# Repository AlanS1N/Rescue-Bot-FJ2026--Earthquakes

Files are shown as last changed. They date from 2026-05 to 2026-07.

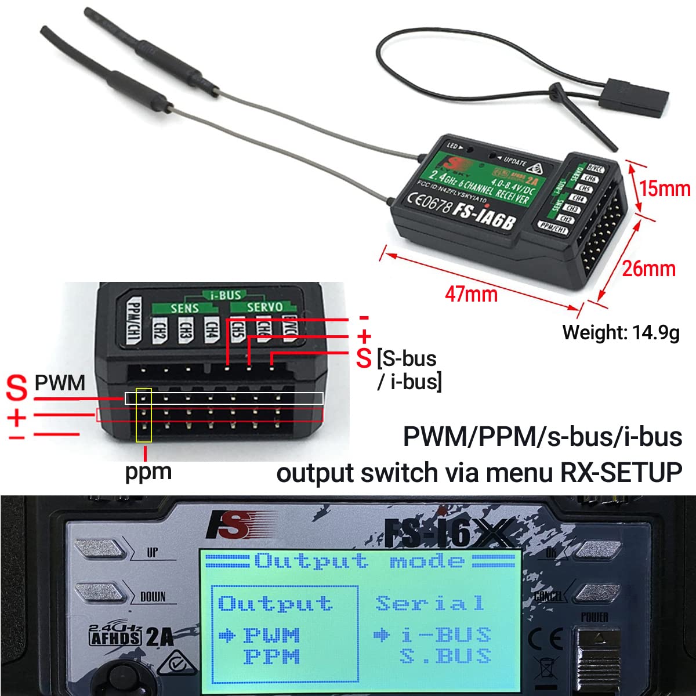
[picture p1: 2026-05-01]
Motor Movement/Image - FlySky Setup Reference.jpg

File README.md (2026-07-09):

# Design and Implementation of a Mobile Robot for Search, Rescue, and Structural Diagnostics in Disaster Scenarios
>[!WARNING]
>This is Work in Progress Project at the Tecnológico de Monterrey Campus Puebla.

banner-RescueBot





 Table of Contents

- [Project Overview](#project-overview)
- [Screenshots and Progress](#screenshots-and-progress)
- [Circuit Connections](#circuit-connections)
- [Materials](#materials)
- [Future Goals](#future-goals)

---

# Project Overview

This project focuses on the analysis of structural damages and failures caused by disasters (earthquakes, landslides, etc.) to identify operational needs for search and rescue in high-risk zones. Based on these findings, we designed and built a terrestrial mobile robot that _will serve both as a machine_ for entering and exploring without endangering first responders, _and as a tool to diagnose estructural damages_ using artificial computer vision.

The system **will be** validated in a simulated disaster scenario to evaluate technical performance, exploration efficiency, and its utility in supporting rescue missions and structural diagnostics.

📜 Click here to <a href="https://www.overleaf.com/read/qfjzchcjjjqq#3e95bf"> VIEW the paper developed alongside the documentation in Github.</a> (WORK IN PROGRESS)

📷 Click here to<a href="https://1024terabox.com/s/1G64Ih9HwfPtlZVFDbBaQSw"> DOWNLOAD the the DATASET used to train the vision system</a>, provided by Dr. Romeo Ballinas González.

👁️ Click here to<a href="https://1024terabox.com/s/1AKwh-wiAku7Wo5QE4bYNWA"> DOWNLOAD the the VISION SYSTEM LOCAL FILES used to train the vision system.</a> (40.6 GiB)

**Key Features:**
  1. Teleoperated movement.
  2. Video transmission through RF.
  3. Camara movement throguh head tracking.
  4. Trained algorithm to detect and diagnose structural damages.
  5. Rocker bogie suspension.

# Screenshots and Progress

<table>
  <tr>
    <td>
      
    </td>
    <td>
      
    </td>
  </tr>
  <tr>
    <td>
      
    </td>
    <td>
      
    </td>
  </tr>
</table>

👉 [Click here to see development logs and check out the current progress](./.docs/progress.md)

# Circuit Connections
The complete circuit diagram is shown below:

Captura desde 2026-06-09 13-00-33

# Materials

The material list used is listed below:

| Name | Units |
|---|---|
| JGB37-520B | 6 |
| Servomotor MG995 | 1 |
| Servomotor MG996 | 1 |
| H Bridge BTS7960 IBT_2  | 2 |
| GY-BNO085 | 1 |
| ESP32 DEVKIT 30 Pines | 2 |
| Jetson Nano Ori | 1 |
| FPV Set TS5823Pro | 1 |
| Logitech C920 Webcam | 1 |
| EMAX Transporter 2 | 1 |
| FlySky FS-i6x Control | 1 |
| FlySky FS-iA6 Rx | 1 |
| PLA Filament | 1 |
| TPU Filament | 1 |
| Perf. phenolic board | 2 |
| Screws(various lengths) |  ±14  |

# Future Goals
This project is planned to be worked on further more with other students at Tecnológico de Monterrey Campus Puebla, under the supervision of Dr. Roberto R. Flores Quintero.

Some current future goals involve:
- 🧠 Deeper training and testing of the computer vision system.
- 🔧 Redisign the structure to for increased stability and access to components
- 🌡️ Adding thermal vision for detecting gases and possible life signals.
- 🕶️ Developing a VR simulated environment.

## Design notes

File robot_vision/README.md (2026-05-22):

# Robot Vision

README de chill para correr la vision del robot en la Jetson y entender como funciona lo del screenshot.

## Que hace

Esta carpeta trae el clasificador de dano/no dano para la camara del robot.

El modelo es un YOLO classifier de Ultralytics. Ojo: no detecta cajas ni marca exactamente donde esta el dano; ve el frame completo y decide una clase:

```text
damage
no_damage
```

El script principal es:

```text
infer_camera.py
```

Ese script abre la camara, corre el modelo en vivo y, si esta conectado al ESP32 por serial, tambien escucha triggers para guardar screenshot.

## Lo del screenshot

Si, esta version ya tiene el trigger.

La idea es:

```text
ESP32 manda por serial: PHOTO_TRIGGER
Python lo lee en infer_camera.py
Python guarda la foto actual con la prediccion dibujada
Python guarda tambien un JSON con metadata
```

El texto tiene que llegar exactamente asi:

```text
PHOTO_TRIGGER
```

Cuando llega, Python guarda archivos en:

```text
robot_vision/captures/
```

Ejemplo de salida:

```text
captures/trigger-20260521-154233.jpg
captures/trigger-20260521-154233.json
```

El `.jpg` es la imagen con el overlay de la prediccion. El `.json` trae cosas como clase, confianza, status y ruta de la imagen.

Ejemplo del mensaje que imprime Python cuando guarda:

```text
photo_saved metadata=captures/trigger-20260521-154233.json class=damage conf=0.932
```

## Archivos importantes

```text
robot_vision/
|-- infer_camera.py        -> corre camara + modelo + trigger PHOTO_TRIGGER
|-- smoke_test.py          -> prueba rapida con una imagen
|-- requirements.txt       -> dependencias de Python
|-- README.md              -> este archivo
|-- models/
|   `-- bestfinal.pt       -> modelo recomendado
`-- captures/              -> aqui se guardan screenshots cuando hay trigger
```

Para correr en el robot, lo importante es:

```text
infer_camera.py
smoke_test.py
requirements.txt
models/bestfinal.pt
```

No hace falta mover datasets, runs, imagenes de entrenamiento ni cosas de preparacion.

## Instalar en la Jetson

Desde el repo del robot:

```bash
cd robot_vision
python3 -m venv .venv
source .venv/bin/activate
pip install -r requirements.txt
```

Si la Jetson ya tiene PyTorch/Ultralytics instalado en otro ambiente, puedes usar ese ambiente y saltarte el `.venv`.

Dependencias de esta carpeta:

```text
ultralytics
opencv-python
pyserial
```

## Probar que el modelo carga

Usa cualquier imagen:

```bash
python3 smoke_test.py /ruta/a/imagen.jpg
```

Salida esperada:

```text
class=damage conf=0.932
```

o:

```text
class=no_damage conf=0.884
```

Si esto funciona, el modelo esta cargando bien.

## Probar camara sin ESP32

Primero prueba que la camara abre:

```bash
python3 infer_camera.py --camera 0 --show
```

Para cerrar la ventana, presiona `q`.

Si no abre, prueba otra camara:

```bash
python3 infer_camera.py --camera 1 --show
```

Modo sin ventana, mas parecido a integracion real:

```bash
python3 infer_camera.py --camera 0
```

El script imprime algo cada medio segundo:

```text
ok class=damage label='Damage' conf=0.932
ok class=no_damage label='No damage' conf=0.884
```

Puedes cambiar cada cuanto imprime:

```bash
python3 infer_camera.py --camera 0 --print-every 0.2
```

Y puedes pedir confianza minima:

```bash
python3 infer_camera.py --camera 0 --min-conf 0.70
```

Si la confianza queda abajo de eso, imprime:

```text
low_conf class=damage label='Damage' conf=0.621
```

## Probar camara CSI con GStreamer

Si la Jetson usa camara CSI, puedes pasar un pipeline GStreamer como `--camera`.

Ejemplo base:

```bash
python3 infer_camera.py --camera "nvarguscamerasrc ! video/x-raw(memory:NVMM), width=640, height=480, framerate=30/1 ! nvvidconv ! video/x-raw, format=BGRx ! videoconvert ! video/x-raw, format=BGR ! appsink" --show
```

Si usas USB webcam, normalmente basta con `--camera 0`.

## Probar el trigger del screenshot en la Jetson

Conecta el ESP32 por USB y revisa que puerto le dio Linux:

```bash
ls /dev/ttyUSB* /dev/ttyACM*
```

Puede ser algo como:

```text
/dev/ttyUSB0
```

o:

```text
/dev/ttyACM0
```

Corre vision con serial:

```bash
python3 infer_camera.py --camera 0 --serial-port /dev/ttyUSB0 --baud 115200 --show
```

Si tu puerto es otro:

```bash
python3 infer_camera.py --camera 0 --serial-port /dev/ttyACM0 --baud 115200 --show
```

Cuando el ESP32 mande `PHOTO_TRIGGER`, Python debe imprimir:

```text
photo_saved metadata=... class=... conf=...
```

Luego revisa:

```bash
ls captures
```

Deberias ver un `.jpg` y un `.json` por cada trigger.

## Probar trigger sin ESP32 real

Si quieres probar solo la parte de Python/serial sin depender del codigo del ESP32, puedes usar dos terminales con un puerto serial virtual. En Jetson normalmente sirve `socat`.

Instala si hace falta:

```bash
sudo apt install socat
```

Terminal 1:

```bash
socat -d -d pty,raw,echo=0 pty,raw,echo=0
```

Eso imprime dos puertos, por ejemplo:

```text
/dev/pts/3
/dev/pts/4
```

Terminal 2, corre vision usando el primer puerto:

```bash
python3 infer_camera.py --camera 0 --serial-port /dev/pts/3 --show
```

Terminal 3, manda el trigger por el segundo puerto:

```bash
printf "PHOTO_TRIGGER\n" > /dev/pts/4
```

Si todo esta bien, se guarda la captura en `captures/`.

## Comando recomendado para integracion real

Para el robot, sin ventana:

```bash
python3 infer_camera.py --camera 0 --serial-port /dev/ttyUSB0 --baud 115200 --capture-dir captures --min-conf 0.70
```

Con ventana para debug:

```bash
python3 infer_camera.py --camera 0 --serial-port /dev/ttyUSB0 --baud 115200 --capture-dir captures --min-conf 0.70 --show
```

## Argumentos utiles

```text
--model         Ruta al modelo .pt. Default: models/bestfinal.pt
--camera        Indice de camara o pipeline GStreamer. Default: 0
--width         Ancho de captura. Default: 640
--height        Alto de captura. Default: 480
--show          Muestra ventana de OpenCV
--min-conf      Confianza minima para status ok
--print-every   Cada cuantos segundos imprime prediccion
--serial-port   Puerto del ESP32, por ejemplo /dev/ttyUSB0
--baud          Baud rate del ESP32. Default: 115200
--capture-dir   Carpeta donde se guardan screenshots. Default: captures
```

## Problemas comunes

Si la camara no abre:

```bash
python3 infer_camera.py --camera 1 --show
```

Si el serial no abre, revisa permisos:

```bash
ls -l /dev/ttyUSB0
```

Puede que necesites agregar tu usuario al grupo `dialout`:

```bash
sudo usermod -a -G dialout $USER
```

Luego cierra sesion y vuelve a entrar.

Si no se guarda screenshot:

```text
1. Confirma que estas pasando --serial-port.
2. Confirma que el ESP32 esta mandando exactamente PHOTO_TRIGGER con salto de linea.
3. Confirma que el baud coincide, normalmente 115200.
4. Mira la consola de Python: debe aparecer photo_saved.
5. Revisa la carpeta captures/.
```

Si el modelo no carga:

```text
1. Revisa que exista models/bestfinal.pt.
2. Corre smoke_test.py con una imagen.
3. Confirma que ultralytics este instalado en el ambiente activo.
```

## Mini resumen

Para probar rapido en Jetson:

```bash
cd robot_vision
source .venv/bin/activate
python3 smoke_test.py /ruta/a/imagen.jpg
python3 infer_camera.py --camera 0 --show
python3 infer_camera.py --camera 0 --serial-port /dev/ttyUSB0 --baud 115200 --show
```

Y cuando el ESP32 mande:

```text
PHOTO_TRIGGER
```

Python toma el frame actual, corre/usa la prediccion actual, guarda screenshot y metadata en:

```text
captures/
```

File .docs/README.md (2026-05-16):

# Design and Implementation of a Mobile Robot for Search, Rescue, and Structural Diagnostics in Disaster Scenarios
>[!WARNING]
>This is Work in Progress Project at the Tecnológico de Monterrey Campus Puebla.

banner-RescueBot





 Table of Contents

- [Project Overview](#project-overview)
- [Screenshots and Progress](#screenshots-and-progress)
- [Circuit Connections](#circuit-connections)
- [Materials](#materials)
- [Future Goals](#future-goals)

---

# Project Overview

This project focuses on the analysis of structural damages and failures caused by disasters (earthquakes, landslides, etc.) to identify operational needs for search and rescue in high-risk zones. Based on these findings, we designed and built a terrestrial mobile robot that _will serve both as a machine_ for entering and exploring without endangering first responders, _and as a tool to diagnose estructural damages_ using artificial computer vision.

The system **will be** validated in a simulated disaster scenario to evaluate technical performance, exploration efficiency, and its utility in supporting rescue missions and structural diagnostics.

📜 (WIP) The paper developed alongside the documentation in Github can be viewwed <a href="https://www.overleaf.com/read/qfjzchcjjjqq#3e95bf">by clicking here.</a>

**Key Features:**
  1. Teleoperated movement.
  2. Video transmission through RF.
  3. Camara movement throguh head tracking.
  4. Trained algorithm to detect and diagnose structural damages.
  5. Rocker bogie suspension.

# Screenshots and Progress

<table>
  <tr>
    <td>
      
    </td>
    <td>
      
    </td>
  </tr>
  <tr>
    <td>
      
    </td>
    <td>
      
    </td>
  </tr>
</table>

👉 [Click here to see development logs and check out the current progress](./progress.md)

# Circuit Connections
The complete circuit diagram is shown below:

Captura desde 2026-05-14 22-33-53

# Materials

The material list used is listed below:

| Name | Units |
|---|---|
| JGB37-520B | 6 |
| Servomotor MG995 | 2 |
| H Bridge BTS7960 IBT_2  | 2 |
| GY-BNO085 | 1 |
| ESP32 DEVKIT 30 Pines | 2 |
| FPV Set TS5823Pro | 1 |
| Logitech C920 Webcam | 1 |
| EMAX Transporter 2 | 1 |
| 1K Ohms Resistor | 2 |

# Future Goals
This project is planned to be worked on further more with other students at Tecnológico de Monterrey Campus Puebla, under the supervision of Dr. Roberto R. Flores Quintero.

Some current future goals involve:
- 🧠 Deeper training and testing of the computer vision system.
- 🌡️ Adding thermal vision for detecting gases and possible life signals.
- 🔧 Adding more useful sensors to the robot.
- 🕶️ Developing a VR simulated environment.

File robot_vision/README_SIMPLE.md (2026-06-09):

# Robot Vision - Guía rápida para la Jetson

Esto es para que pruebes primero el programa y luego lo dejes arrancar solo al encender.

## Paso 1 - Ir a la carpeta correcta

```bash
cd ~/Desktop/rescue_robot/Final_old/robot_vision
```|

## Paso 2 - Activar el entorno virtual

```bash
source .venv/bin/activate
```

Si no existe `.venv`, créalo con:

```bash
python3 -m venv .venv
source .venv/bin/activate
pip install -r requirements.txt
```

## Paso 3 - Arreglar la compatibilidad de NumPy

Tu error actual dice que NumPy 2.x no funciona con Torch/Ultralytics.

Haz esto dentro del venv:

```bash
python3 -m pip install --upgrade pip
python3 -m pip install "numpy<2"
python3 -m pip install -r requirements.txt
```

Si el error persiste y todavía ve paquetes desde `/home/<usuario>/.local`, fuerza que Python NO use paquetes de usuario:

```bash
export PYTHONNOUSERSITE=1
python3 -m pip install "numpy<2"
python3 -m pip install -r requirements.txt
```

### Si sigues con problemas, recrea el venv limpio

```bash
cd ~/Desktop/rescue_robot/Final_old/robot_vision
rm -rf .venv
python3 -m venv .venv
source .venv/bin/activate
python3 -m pip install --upgrade pip
export PYTHONNOUSERSITE=1
python3 -m pip install "numpy<2"
python3 -m pip install -r requirements.txt
```

Con eso se asegura que el entorno use versiones compatibles y no mezcle paquetes de usuario.

## Paso 4 - Probar el programa manualmente

Antes de tocar el service, prueba que esto funcione:

```bash
python3 infer_camera.py --camera 0
```

Si estás delante de la Jetson y quieres ver la cámara:

```bash
SHOW_WINDOW=true python3 infer_camera.py --camera 0
```

### Qué debe pasar

- El script debe arrancar y quedarse ejecutando
- Debe leer la cámara `/dev/video0` o el índice correcto
- Debe mostrar mensajes de `ok` o `low_conf` cada cierto tiempo

Si se cierra rápido, no sigas aún con el servicio.

## Paso 4.1 - Si no abre la cámara

Si ves este error:

```text
No pude abrir la camara. Prueba --camera 1 o revisa el pipeline.
```

haz esto:

```bash
ls /dev/video*
v4l2-ctl --list-devices
```

Si aparece `/dev/video1`, prueba:

```bash
SHOW_WINDOW=true python3 infer_camera.py --camera 1
```

Si tu cámara es una cámara NVIDIA/Jetson integrada, prueba la pipeline de GStreamer:

```bash
python3 infer_camera.py --camera "nvarguscamerasrc ! video/x-raw(memory:NVMM), width=640, height=480, framerate=30/1 ! nvvidconv ! video/x-raw, format=BGRx ! videoconvert ! video/x-raw, format=BGR ! appsink"
```

Si `v4l2-ctl` no existe, instálalo con:

```bash
sudo apt install v4l-utils
```

Solo sigue al servicio cuando puedas abrir la cámara sin error.

## Paso 5 - Configurar el service para arrancar al boot

```bash
chmod +x start_vision.sh
sudo cp robot-vision.service /etc/systemd/system/
sudo systemctl daemon-reload
sudo systemctl enable robot-vision.service
sudo systemctl restart robot-vision.service
```

## Paso 6 - Verificar el servicio

```bash
sudo systemctl status robot-vision.service
sudo journalctl -u robot-vision.service -f
```

Si ves que el service sigue reiniciando y saliendo con `status=1`, entonces el programa aún no corre bien.

## Paso 7 - Probar reinicio de la Jetson

Si ya funciona manualmente y el service se mantiene activo:

```bash
sudo reboot
```

Luego, al volver a conectar por SSH:

```bash
sudo systemctl status robot-vision.service
sudo journalctl -u robot-vision.service -n 50 --no-pager
```

## Nota importante

- El service no debe usar `--show` automáticamente.
- Si quieres ver la pantalla, hazlo manualmente con `SHOW_WINDOW=true`.
- Primero asegúrate de que `python3 infer_camera.py --camera 0` funcione.
- Solo después habilita `systemctl enable robot-vision.service`.

## Diagnóstico rápido

Si algo falla, revisa esto:

```bash
ls -l models/bestfinal.pt
python3 infer_camera.py --camera 0 2>&1 | tee /tmp/infer_debug.txt
```

Eso te dirá si falta el modelo o si hay error de librerías.

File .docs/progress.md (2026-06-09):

# 📚 **Development Progress**
👉 [Back to Main Description](https://github.com/AlanS1N/Rescue-Bot-FJ2026--Earthquakes)

### Table of Contents
- [CAD Design](#-cad-design)
- [Electronics](#-electronics)
- [Computer Vision](#-computer-vision)
- [Teleoperated Control](#-teleoperated-control)
- [Head Tracking](#-head-tracking)
- [Batteries](#-batteries-implementation)
- [Complete Integration](#-complete-integration)
---

---
# 🛠 CAD Design
### 📌 Progress
- Initial chassis structure completed: Made "legs" out of PVC and component box of PLA.
- Wheels and rims installed: Both custom designed, rims printed with PLA and wheels printed with TPU.
- Rocker-bogie dimensions adjusted: Alligned the wheels.

### 🖼 Preview (Solidworks)


---

# ⚡ Electronics
### 📌 Progress
- FlySky components integrated: RX and controller fully integrated and tested.
- PCBs for circuits completed: Made custom PCB for ESP32 with IMU.
- Servo mechanism with IMU implemented: Cameras slots and movement implemented.

### 🎥 Video
Video_Github

---

# 💻 Computer Vision
### 📌 Progress
- Database collected: Received database for training model.
- Yolo model prototype: Functional prototype tested.

### 🎥 Video
Modelo_Test

---

# 🎮 Teleoperated Control
### 📌 Progress
- Motors fully operational: H-Bridges connected to all 6 motors and working.
- ESP and controller connected: Recieves signal and moves motors in given direction.

### 🎥 Video
Movement_Tests

---

# 🥽 Head Tracking
### 📌 Progress
- ESP-Now protocol implemented: Communication without Wi-Fi nor Bluetooth between circuits.
- Servos moving according to IMU.

### 🎥 Video
Visor_TEst

---

# 🔋 Batteries implementation
### 📌 Progress
- Soldered cables to energize dedicated components.
- Added switches to turn on energy easily,

### 🖼 Preview (Solidworks)
Batteries

---

# ✅ Complete Integration
### 📌 Progress
- Make adjustments for all components to be interconnected and functional.
- ESP32 recieves communication through ESP-NOW and the controller.
- ESP32 controls all logic succesfully.

### 🎥 Video
Integration

---
👉 [Back to Main Description](https://github.com/AlanS1N/Rescue-Bot-FJ2026--Earthquakes)

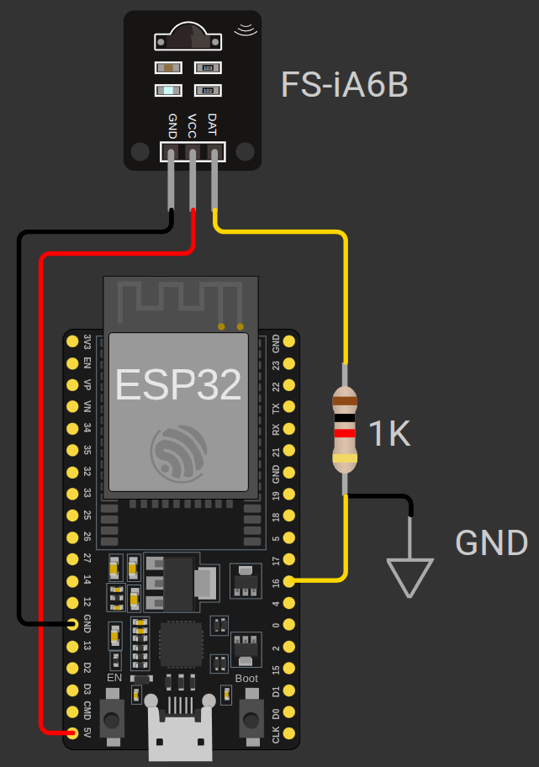
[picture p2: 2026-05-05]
Motor Movement/Image - FS-iA6B to ESP32.png

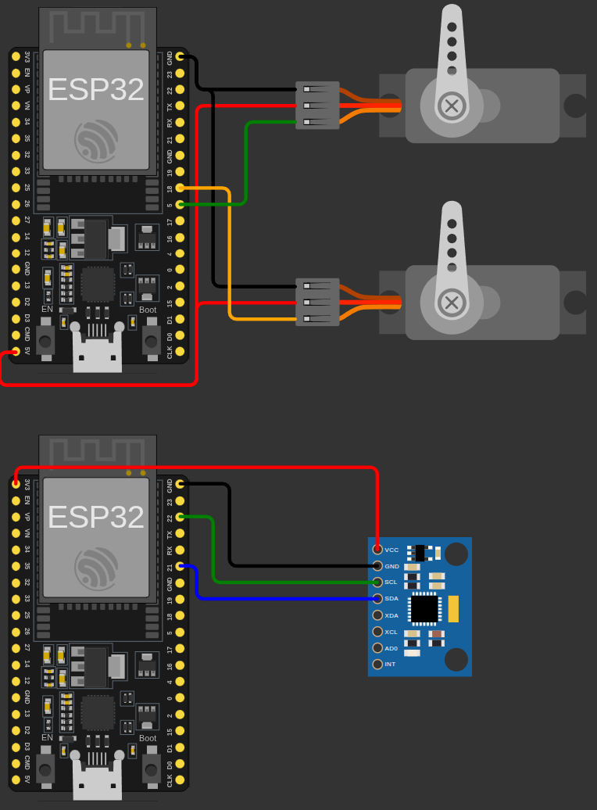
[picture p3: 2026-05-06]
Camera Head Tracking/Image - Circuit Diagram (1).png

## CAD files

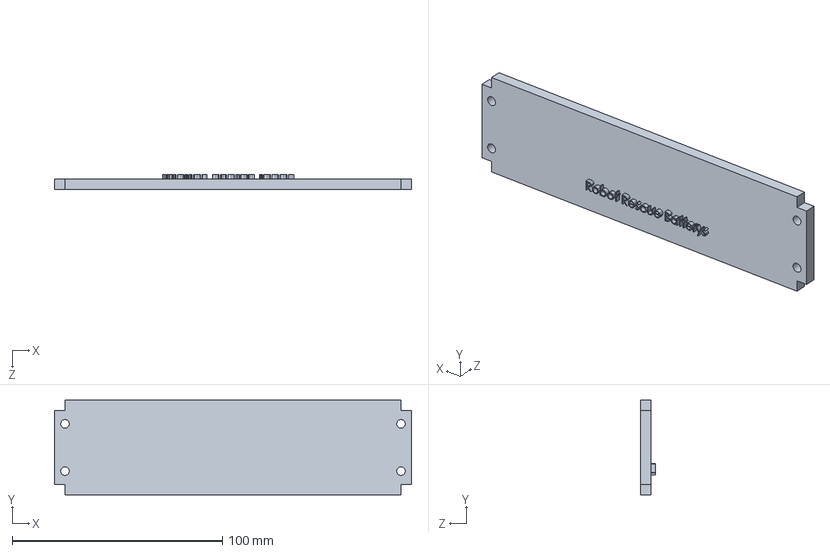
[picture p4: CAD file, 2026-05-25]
.3D Models/TapaCajaPilas.SLDPRT
170.0 x 45.0 x 7.00 mm

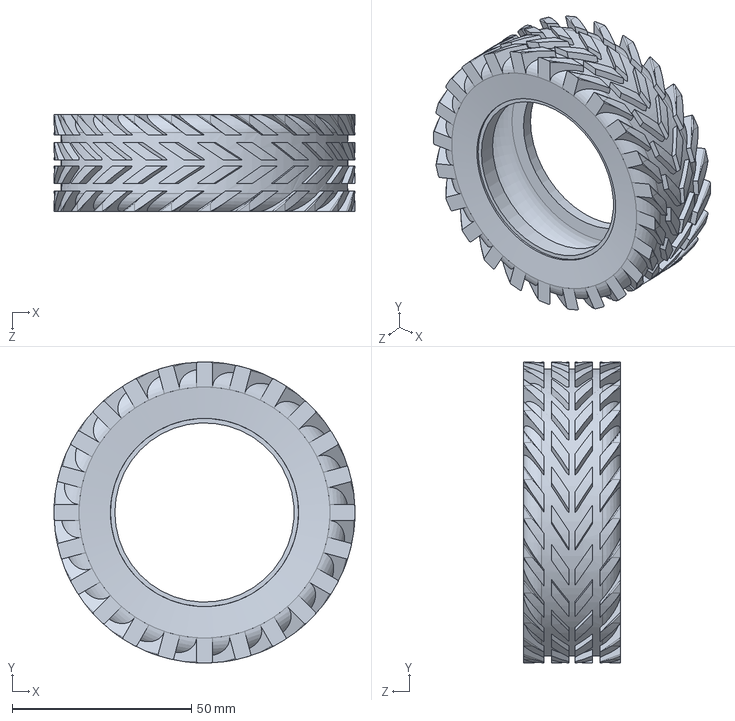
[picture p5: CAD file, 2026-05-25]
.3D Models/LlantaFinal.SLDPRT
84.0 x 84.0 x 27.0 mm

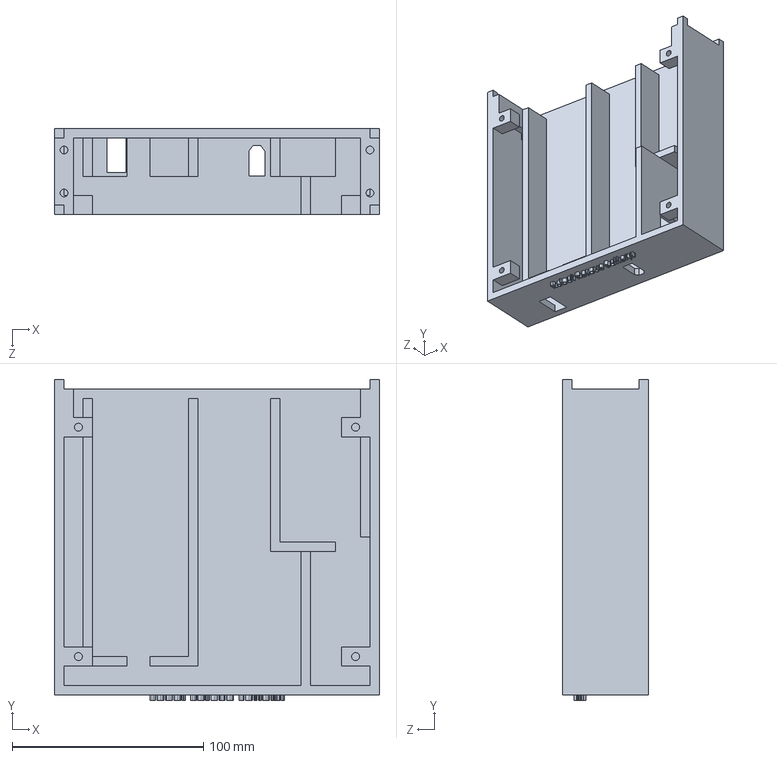
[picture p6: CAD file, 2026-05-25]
.3D Models/CajaParaPilas1.SLDPRT
170.0 x 168.0 x 45.0 mm

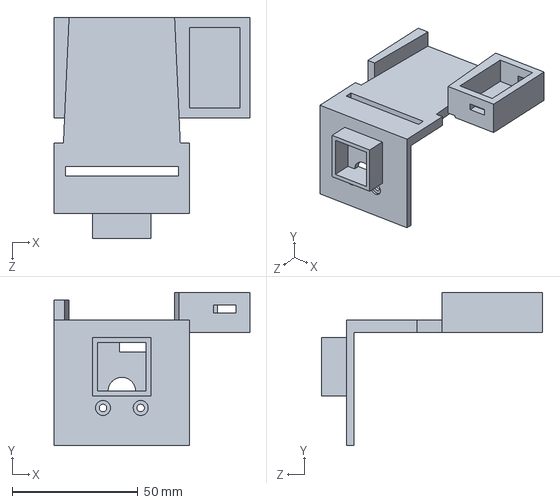
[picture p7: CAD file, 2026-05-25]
.3D Models/soportecamfinal.SLDPRT
78.0 x 61.0 x 88.0 mm

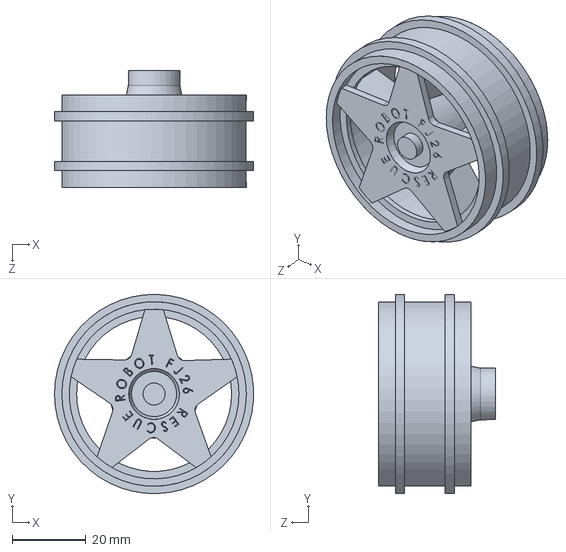
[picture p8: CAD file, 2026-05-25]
.3D Models/llanta roja p2.SLDPRT
53.9 x 54.0 x 31.6 mm

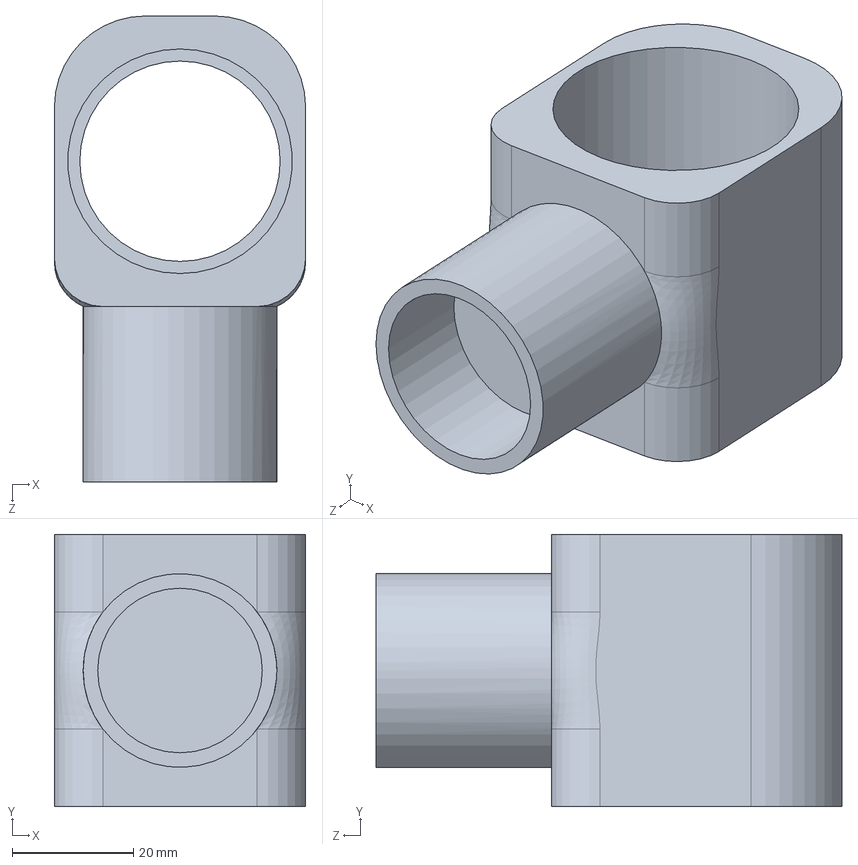
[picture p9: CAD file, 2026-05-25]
.3D Models/MotorEncople.SLDPRT
41.5 x 45.0 x 77.0 mm

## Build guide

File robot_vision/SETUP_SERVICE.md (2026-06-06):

# Setup Automático - Robot Vision Service

## ¿Qué hace?
- **Corre automáticamente al iniciar la Jetson** sin necesidad de SSH
- **Detecta automáticamente el puerto serial** (USB0 o ACM0)
- **Guarda logs** en `robot_vision/logs/` con timestamp
- **Reinicia automáticamente** si falla
- **Cámara 0 fija** (sin necesidad de cambiar parámetros)
- **Corre headless**: no usa `--show` en el servicio systemd

## Instalación en la Jetson

### 1. Copiar archivos
```bash
cd ~/robot_vision
# Los archivos ya deben estar aquí:
# - start_vision.sh
# - robot-vision.service
```

### 2. Dar permisos al script
```bash
chmod +x ~/robot_vision/start_vision.sh
```

### 3. Copiar service a systemd
```bash
sudo cp ~/robot_vision/robot-vision.service /etc/systemd/system/
```

### 4. Recargar systemd
```bash
sudo systemctl daemon-reload
```

### 5. Habilitar el service (para que corra al boot)
```bash
sudo systemctl enable robot-vision.service
```

### 6. Iniciar el service (opcional, si no quieres esperar al reboot)
```bash
sudo systemctl start robot-vision.service
```

---

## Comandos útiles

### Ver estado del service
```bash
sudo systemctl status robot-vision.service
```

### Ver logs en vivo
```bash
sudo journalctl -u robot-vision.service -f
```

### Ver logs de una hora específica
```bash
sudo journalctl -u robot-vision.service --since "2026-06-04 10:00:00"
```

### Ver logs guardados en archivo
```bash
ls ~/robot_vision/logs/
cat ~/robot_vision/logs/vision_20260604_101234.log
```

### Parar el service
```bash
sudo systemctl stop robot-vision.service
```

### Reiniciar el service
```bash
sudo systemctl restart robot-vision.service
```

### Deshabilitar el service (no corra al boot)
```bash
sudo systemctl disable robot-vision.service
```

---

## Troubleshooting

### El service no inicia
```bash
sudo systemctl status robot-vision.service
# Ver el error específico
```

### Permisos del puerto serial
Si ves "Permission denied" en los logs:
```bash
sudo usermod -a -G dialout jetson
# Luego logout y login de nuevo
```

### Ver si el puerto está siendo detectado
```bash
ls /dev/ttyUSB* /dev/ttyACM*
```

### Ver logs del service en tiempo real
```bash
sudo journalctl -u robot-vision.service -f --no-pager
```

### El venv no se crea bien
```bash
# Borrar el venv y dejar que el script lo recree
rm -rf ~/robot_vision/.venv
sudo systemctl restart robot-vision.service
```

---

## Automatización adicional (opcional)

Si quieres **parar el service sin usar SSH**:

1. Crea un archivo vacío que signifique "parar"
2. Modifica el script para checarlo

O usa:
```bash
# Parar remotamente
ssh jetson@<IP> "sudo systemctl stop robot-vision.service"
```

---

## Flujo después de boot

1. Jetson arranca
2. systemd inicia el service automáticamente
3. Script detecta puerto serial
4. Corre `infer_camera.py` con los parámetros correctos
5. Logs se guardan en `logs/vision_TIMESTAMP.log`
6. Si falla, reintentar después de 10 segundos

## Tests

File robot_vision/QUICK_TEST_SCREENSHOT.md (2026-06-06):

# Prueba rapida: trigger + screenshot en Jetson

Objetivo: comprobar que el ESP32 manda el trigger y que la Jetson guarda aunque sea una screenshot.

## 1. Cargar el codigo al ESP32

En Arduino IDE:

1. Abre el sketch del ESP32.
2. Selecciona la placa ESP32 correcta.
3. Selecciona el puerto USB del ESP32.
4. Sube el codigo.

Lo importante es que, cuando quieras tomar foto, el ESP32 mande esto por Serial:

```cpp
Serial.println("PHOTO_TRIGGER");
```

El baud debe coincidir con Python. Recomendado:

```cpp
Serial.begin(115200);
```

## 2. Conectar ESP32 a la Jetson

Conecta el ESP32 a la Jetson por USB.

En la Jetson corre:

```bash
ls /dev/ttyUSB* /dev/ttyACM*
```

Normalmente sera uno de estos:

```text
/dev/ttyUSB0
/dev/ttyACM0
```

Ese es el puerto que vas a usar en `--serial-port`.

## 3. Entrar a robot_vision

```bash
cd robot_vision
source .venv/bin/activate
```

Si todavia no tienes el ambiente:

```bash
python3 -m venv .venv
source .venv/bin/activate
pip install -r requirements.txt
```

## 4. Probar que la camara abre

Primero sin ESP32:

```bash
python3 infer_camera.py --camera 0 --show
```

Si no abre:

```bash
python3 infer_camera.py --camera 1 --show
```

Para salir, presiona `q`.

## 5. Correr vision escuchando al ESP32

Si tu puerto fue `/dev/ttyUSB0`:

```bash
python3 infer_camera.py --camera 0 --serial-port /dev/ttyUSB0 --baud 115200 --sho
```

Si tu puerto fue `/dev/ttyACM0`:

```bash
python3 infer_camera.py --camera 0 --serial-port /dev/ttyACM0 --baud 115200 --show
```

Deja esa terminal corriendo.

## 6. Disparar el trigger

Ahora haz que el ESP32 mande:

```text
PHOTO_TRIGGER
```

Puede ser por boton, por tu logica del robot, o temporalmente con algo simple en Arduino:

```cpp
void setup() {
  Serial.begin(115200);
}

void loop() {
  Serial.println("PHOTO_TRIGGER");
  delay(3000);
}
```

Con ese sketch de prueba, debe tomar una screenshot cada 3 segundos.

## 7. Confirmar que si guardo

Cuando Python recibe el trigger, en la terminal debe salir algo asi:

```text
photo_saved metadata=captures/trigger-20260521-154233.json class=damage conf=0.932
```

Revisa la carpeta:

```bash
ls captures
```

Debes ver archivos tipo:

```text
trigger-20260521-154233.jpg
trigger-20260521-154233.json
```

Abre el `.jpg` y listo: esa es la screenshot tomada por trigger.

## Comando final mas probable

Este es el que casi seguro vas a usar:

```bash
cd robot_vision
source .venv/bin/activate
python3 infer_camera.py --camera 0 --serial-port /dev/ttyUSB0 --baud 115200 --show
```

Si el ESP32 aparece como ACM:

```bash
python3 infer_camera.py --camera 0 --serial-port /dev/ttyACM0 --baud 115200 --show
```

## Si no jala

Si no aparece `photo_saved`:

1. Revisa que el ESP32 mande exactamente `PHOTO_TRIGGER`.
2. Revisa que tenga salto de linea: usa `Serial.println`, no `Serial.print`.
3. Revisa que el baud sea `115200` en ambos lados.
4. Revisa que estes usando el puerto correcto.
5. Revisa permisos del puerto:

```bash
ls -l /dev/ttyUSB0
sudo usermod -a -G dialout $USER
```

Despues de cambiar grupo, cierra sesion y entra otra vez.

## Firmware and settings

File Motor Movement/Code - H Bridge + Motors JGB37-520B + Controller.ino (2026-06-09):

// ============================================================
// ROCKER BOGIE ROVER
// + ESP-NOW HEAD TRACKING RX
// + PHOTO TRIGGER
// ============================================================

#include <WiFi.h>
#include <esp_now.h>
#include <esp_wifi.h>

#include <ESP32Servo.h>
#include <ESP32PWM.h>

#define ESPNOW_CHANNEL 1

// ============================================================
// ESP-NOW DATA
// ============================================================

typedef struct {
  float yaw;
  float roll;
} DataPacket;

DataPacket latestData;
volatile bool newData = false;

// ============================================================
// RIGHT IBT2
// ============================================================

Servo servoYaw;
Servo servoRoll;

float currentYaw = 90;
float currentRoll = 90;

const int YAW_MIN = 5;
const int YAW_MAX = 175;

const int ROLL_MIN = 30;
const int ROLL_MAX = 150;

// ============================================================
// LEFT IBT2
// ============================================================

const int RPWM_L = 32;
const int LPWM_L = 33;
const int R_EN_L = 26;
const int L_EN_L = 25;

// ============================================================
// RIGHT IBT2
// ============================================================

const int RPWM_R = 14;
const int LPWM_R = 27;
const int R_EN_R = 13;
const int L_EN_R = 12;


// ============================================================
// IBUS
// ============================================================

const int IBUS_MIN = 1000;
const int IBUS_MID = 1500;
const int IBUS_MAX = 2000;
const int IBUS_DEADZONE = 35;

uint16_t chSteering = IBUS_MID;
uint16_t chThrottle = IBUS_MID;
uint16_t chSWA = 1000;

bool swaActivoAnterior = false;
unsigned long ultimaLectura = 0;

// ============================================================
// DRIVE TUNING
// ============================================================

const int PWM_MAX = 230;
const int PWM_START = 75;

const int TURN_PWM_MAX = 210;
const int TURN_PWM_START = 90;

const int RAMP_STEP = 8;

int velIzqActual = 0;
int velDerActual = 0;

// DEBUG
unsigned long ultimoDebug = 0;
const unsigned long DEBUG_INTERVAL = 100;

// ============================================================
// ESP-NOW CALLBACK
// ============================================================

void onReceive(
  const esp_now_recv_info *info,
  const uint8_t *data,
  int len
) {

  if (len != sizeof(latestData)) {
    return;
  }

  memcpy(
    &latestData,
    data,
    sizeof(latestData)
  );

  newData = true;
}

// ============================================================
// IBUS READER
// ============================================================

void leerIBus() {

  while (Serial2.available()) {

    static uint8_t buffer[32];
    static uint8_t indice = 0;

    uint8_t b = Serial2.read();

    if (indice == 0 && b != 0x20) continue;

    if (indice == 1 && b != 0x40) {
      indice = 0;
      continue;
    }

    buffer[indice++] = b;

    if (indice == 32) {

      uint16_t tempCH1 = buffer[2] | (buffer[3] << 8);
      uint16_t tempCH2 = buffer[4] | (buffer[5] << 8);
      uint16_t tempCH7 = buffer[14] | (buffer[15] << 8);

      if (canalValido(tempCH1)) {
        chThrottle =
          (chThrottle * 0.5) +
          (tempCH1 * 0.5);
      }

      if (canalValido(tempCH2)) {
        chSteering =
          (chSteering * 0.5) +
          (tempCH2 * 0.5);
      }

      if (tempCH7 >= 800 &&
          tempCH7 <= 2200) {
        chSWA = tempCH7;
      }

      ultimaLectura = millis();

      indice = 0;
    }
  }
}

// ============================================================
// SETUP
// ============================================================

void setup() {

  Serial.begin(115200);

  // ----------------------------------------------------------
  // iBUS
  // ----------------------------------------------------------

  Serial2.begin(
    115200,
    SERIAL_8N1,
    16,
    -1
  );

  // ----------------------------------------------------------
  // WIFI / ESP-NOW
  // ----------------------------------------------------------

  WiFi.disconnect(true);

  WiFi.mode(WIFI_STA);

  delay(500);

  esp_wifi_set_channel(
    ESPNOW_CHANNEL,
    WIFI_SECOND_CHAN_NONE
  );

  if (esp_now_init() != ESP_OK) {

    Serial.println(
      "ESP-NOW INIT FAILED"
    );

    while (true);
  }

  esp_now_register_recv_cb(
    onReceive
  );

  // ----------------------------------------------------------
  // SERVOS
  // ----------------------------------------------------------

  ESP32PWM::allocateTimer(0);

  servoYaw.setPeriodHertz(50);
  servoRoll.setPeriodHertz(50);

  servoYaw.attach(21, 500, 2500);
  servoRoll.attach(19, 500, 2500);

  servoYaw.write(90);
  servoRoll.write(90);

  // ----------------------------------------------------------
  // MOTOR DRIVERS
  // ----------------------------------------------------------

  pinMode(R_EN_R, OUTPUT);
  pinMode(L_EN_R, OUTPUT);
  pinMode(R_EN_L, OUTPUT);
  pinMode(L_EN_L, OUTPUT);

  digitalWrite(R_EN_R, HIGH);
  digitalWrite(L_EN_R, HIGH);
  digitalWrite(R_EN_L, HIGH);
  digitalWrite(L_EN_L, HIGH);

  ledcAttach(RPWM_R, 20000, 8);
  ledcAttach(LPWM_R, 20000, 8);

  ledcAttach(RPWM_L, 20000, 8);
  ledcAttach(LPWM_L, 20000, 8);

  frenar();
  // ----------------------------------------------------------
  // PRINT MAC ADDRESS
  // ----------------------------------------------------------

  Serial.print("RX MAC: ");
  Serial.println(WiFi.macAddress());
  Serial.println("ROVER READY");
}

// ============================================================
// LOOP
// ============================================================

void loop() {

  leerIBus();

  revisarSWA();

  actualizarHeadTracking();

  if (millis() - ultimaLectura > 300) {

    frenar();

    return;
  }

  int throttle =
    mapCanal(
      chThrottle,
      PWM_MAX,
      PWM_START
    );

  int steering =
    mapCanal(
      chSteering,
      PWM_MAX,
      PWM_START
    );

  int velIzq = 0;
  int velDer = 0;

  if (throttle == 0 &&
      steering != 0) {

    int giro =
      escalarPWM(
        steering,
        TURN_PWM_MAX,
        TURN_PWM_START
      );

    velIzq = -giro;
    velDer = giro;

  } else {

    velIzq =
      throttle - steering;

    velDer =
      throttle + steering;
  }

  velIzq =
    constrain(
      velIzq,
      -255,
      255
    );

  velDer =
    constrain(
      velDer,
      -255,
      255
    );

  velIzqActual =
    aplicarRampa(
      velIzqActual,
      velIzq
    );

  velDerActual =
    aplicarRampa(
      velDerActual,
      velDer
    );

  moverMotores(
    velIzqActual,
    velDerActual
  );

  if (millis() - ultimoDebug >= DEBUG_INTERVAL) {

    ultimoDebug = millis();

    Serial.print("CH1:");
    Serial.print(chSteering);

    Serial.print(" CH2:");
    Serial.print(chThrottle);

    Serial.print(" CH7:");
    Serial.print(chSWA);

    Serial.print(" THR:");
    Serial.print(throttle);

    Serial.print(" STR:");
    Serial.print(steering);

    Serial.print(" L:");
    Serial.print(velIzqActual);

    Serial.print(" R:");
    Serial.print(velDerActual);

    Serial.print(" | Yaw:");
    Serial.print(latestData.yaw, 1);

    Serial.print(" Roll:");
    Serial.print(latestData.roll, 1);

    Serial.print(" ServoYaw:");
    Serial.print(currentYaw, 1);

    Serial.print(" ServoRoll:");
    Serial.println(currentRoll, 1);
  }

  delay(5);
}

// ============================================================
// HEAD TRACKING
// ============================================================

void actualizarHeadTracking() {

  if (!newData) return;

  newData = false;

  float yaw = latestData.yaw;
  float roll = latestData.roll;

  float yawServoPos =
    map(
      yaw,
      -90,
      90,
      YAW_MIN,
      YAW_MAX
    );

  float rollServoPos =
    map(
      roll,
      -45,
      45,
      ROLL_MIN,
      ROLL_MAX
    );

  yawServoPos =
    constrain(
      yawServoPos,
      YAW_MIN,
      YAW_MAX
    );

  rollServoPos =
    constrain(
      rollServoPos,
      ROLL_MIN,
      ROLL_MAX
    );

  currentYaw +=
    (yawServoPos - currentYaw)
    * 0.12;

  currentRoll +=
    (rollServoPos - currentRoll)
    * 0.12;

  servoYaw.write(
    (int)currentYaw
  );

  servoRoll.write(
    (int)currentRoll
  );
}

// ============================================================
// PHOTO TRIGGER
// ============================================================

void revisarSWA() {

  bool swaActivo =
    chSWA > 1500;

  if (
    swaActivo &&
    !swaActivoAnterior
  ) {

    Serial.println(
      "PHOTO_TRIGGER"
    );
  }

  swaActivoAnterior =
    swaActivo;
}

// ============================================================
// HELPERS
// ============================================================

bool canalValido(uint16_t canal) {
  return canal >= 900 &&
         canal <= 2100;
}

int mapCanal(
  uint16_t canal,
  int pwmMax,
  int pwmStart
) {

  int offset =
    canal - IBUS_MID;

  if (abs(offset)
      < IBUS_DEADZONE)
    return 0;

  int salida;

  if (offset > 0) {

    salida =
      map(
        offset,
        IBUS_DEADZONE,
        IBUS_MAX - IBUS_MID,
        pwmStart,
        pwmMax
      );

  } else {

    salida =
      -map(
        abs(offset),
        IBUS_DEADZONE,
        IBUS_MID - IBUS_MIN,
        pwmStart,
        pwmMax
      );
  }

  return constrain(
    salida,
    -pwmMax,
    pwmMax
  );
}

int escalarPWM(
  int valor,
  int pwmMax,
  int pwmStart
) {

  if (valor == 0)
    return 0;

  int salida =
    map(
      abs(valor),
      PWM_START,
      PWM_MAX,
      pwmStart,
      pwmMax
    );

  salida =
    constrain(
      salida,
      pwmStart,
      pwmMax
    );

  return valor > 0 ?
         salida :
         -salida;
}

int aplicarRampa(
  int actual,
  int objetivo
) {

  if (actual < objetivo)
    return min(
      actual + RAMP_STEP,
      objetivo
    );

  if (actual > objetivo)
    return max(
      actual - RAMP_STEP,
      objetivo
    );

  return actual;
}

// ============================================================
// MOTORS
// ============================================================

void moverMotores(
  int izq,
  int der
) {

  if (izq > 0) {

    ledcWrite(RPWM_L, izq);
    ledcWrite(LPWM_L, 0);

  } else {

    ledcWrite(RPWM_L, 0);
    ledcWrite(LPWM_L, abs(izq));
  }

  der = -der;

  if (der > 0) {

    ledcWrite(RPWM_R, der);
    ledcWrite(LPWM_R, 0);

  } else {

    ledcWrite(RPWM_R, 0);
    ledcWrite(LPWM_R, abs(der));
  }
}

// ============================================================
// BRAKE
// ============================================================

void frenar() {

  velIzqActual = 0;
  velDerActual = 0;

  ledcWrite(RPWM_L, 0);
  ledcWrite(LPWM_L, 0);

  ledcWrite(RPWM_R, 0);
  ledcWrite(LPWM_R, 0);
}

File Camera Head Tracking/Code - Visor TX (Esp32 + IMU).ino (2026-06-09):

/////////////////////////////////////////////////////////
//        ESP-NOW TX + BNO08X (YAW + ROLL)            //
/////////////////////////////////////////////////////////

#include <WiFi.h>
#include <esp_now.h>
#include <esp_wifi.h>

#include <Wire.h>
#include <Adafruit_BNO08x.h>

/////////////////////////////////////////////////////////
// SETTINGS
/////////////////////////////////////////////////////////

#define ESPNOW_CHANNEL 1

/////////////////////////////////////////////////////////
// RX MAC ADDRESS          !! MUST CHANGE WITH PROPER !!
/////////////////////////////////////////////////////////

uint8_t receiverAddress[] = {
  0x20, 0xE7, 0xC8, 0x67, 0x6F, 0xF8
};

/////////////////////////////////////////////////////////
// DATA STRUCTURE
/////////////////////////////////////////////////////////

typedef struct {

  float yaw;
  float roll;

} DataPacket;

DataPacket data;

/////////////////////////////////////////////////////////
// IMU
/////////////////////////////////////////////////////////

Adafruit_BNO08x bno08x;

sh2_SensorValue_t sensorValue;

/////////////////////////////////////////////////////////
// OFFSETS
/////////////////////////////////////////////////////////

float yawOffset = 0;
float rollOffset = 0;

bool calibrated = false;

/////////////////////////////////////////////////////////
// SEND CALLBACK
/////////////////////////////////////////////////////////

void onDataSent(
  const wifi_tx_info_t *info,
  esp_now_send_status_t status
) {

  if (status == ESP_NOW_SEND_SUCCESS) {

    Serial.println("Delivery Success");
  }
  else {

    Serial.println("Delivery Failed");
  }
}

/////////////////////////////////////////////////////////
// SETUP
/////////////////////////////////////////////////////////

void setup() {

  Serial.begin(115200);

  delay(2000);

  Serial.println();
  Serial.println("=================================");
  Serial.println("      BNO08X YAW + ROLL TX");
  Serial.println("=================================");

  /////////////////////////////////////////////////////////
  // I2C
  /////////////////////////////////////////////////////////

  Wire.begin(21, 19);

  Wire.setClock(50000);

  /////////////////////////////////////////////////////////
  // BNO08X
  /////////////////////////////////////////////////////////

  Serial.println("Initializing BNO08X...");

  if (!bno08x.begin_I2C(0x4B)) {

    Serial.println("Trying 0x4A...");

    if (!bno08x.begin_I2C(0x4A)) {

      Serial.println("BNO08X NOT FOUND");

      while (1);
    }
  }¿

  Serial.println("BNO08X READY");

  /////////////////////////////////////////////////////////
  // GAME ROTATION VECTOR
  /////////////////////////////////////////////////////////

  bno08x.enableReport(
    SH2_GAME_ROTATION_VECTOR
  );

  /////////////////////////////////////////////////////////
  // WIFI
  /////////////////////////////////////////////////////////

  WiFi.disconnect(true);

  delay(1000);

  WiFi.mode(WIFI_STA);

  delay(1000);

  esp_wifi_set_promiscuous(true);

  esp_wifi_set_channel(
    ESPNOW_CHANNEL,
    WIFI_SECOND_CHAN_NONE
  );

  esp_wifi_set_promiscuous(false);

  /////////////////////////////////////////////////////////
  // PRINT MAC
  /////////////////////////////////////////////////////////

  Serial.print("TX MAC: ");

  Serial.println(WiFi.macAddress());

  /////////////////////////////////////////////////////////
  // ESP-NOW
  /////////////////////////////////////////////////////////

  if (esp_now_init() != ESP_OK) {

    Serial.println("ESP-NOW INIT FAILED");

    return;
  }

  esp_now_register_send_cb(onDataSent);

  /////////////////////////////////////////////////////////
  // PEER
  /////////////////////////////////////////////////////////

  esp_now_peer_info_t peerInfo = {};

  memcpy(
    peerInfo.peer_addr,
    receiverAddress,
    6
  );

  peerInfo.channel = ESPNOW_CHANNEL;

  peerInfo.encrypt = false;

  peerInfo.ifidx = WIFI_IF_STA;

  if (esp_now_add_peer(&peerInfo) != ESP_OK) {

    Serial.println("FAILED TO ADD PEER");

    return;
  }

  Serial.println("TX READY");

  Serial.println("=================================");
}

/////////////////////////////////////////////////////////
// LOOP
/////////////////////////////////////////////////////////

void loop() {

  if (bno08x.getSensorEvent(&sensorValue)) {

    if (sensorValue.sensorId ==
        SH2_GAME_ROTATION_VECTOR) {

      /////////////////////////////////////////////////////
      // QUATERNIONS
      /////////////////////////////////////////////////////

      float qx =
        sensorValue.un.rotationVector.i;

      float qy =
        sensorValue.un.rotationVector.j;

      float qz =
        sensorValue.un.rotationVector.k;

      float qw =
        sensorValue.un.rotationVector.real;

      /////////////////////////////////////////////////////
      // YAW
      /////////////////////////////////////////////////////

      float yaw = atan2(
        2.0 * (qw*qz + qx*qy),
        1.0 - 2.0 *
        (qy*qy + qz*qz)
      ) * 180.0 / PI;

      /////////////////////////////////////////////////////
      // ROLL
      /////////////////////////////////////////////////////

      float roll = atan2(
        2.0 * (qw*qx + qy*qz),
        1.0 - 2.0 *
        (qx*qx + qy*qy)
      ) * 180.0 / PI;

      /////////////////////////////////////////////////////
      // INITIAL CALIBRATION
      /////////////////////////////////////////////////////

      if (!calibrated) {

        yawOffset = yaw;

        rollOffset = roll;

        calibrated = true;

        Serial.println("CENTER POSITION SAVED");
      }

      /////////////////////////////////////////////////////
      // RELATIVE MOVEMENT
      /////////////////////////////////////////////////////

      float relativeYaw =
        yaw - yawOffset;

      float relativeRoll =
        roll - rollOffset;

      /////////////////////////////////////////////////////
      // FIX WRAPAROUND
      /////////////////////////////////////////////////////

      if (relativeYaw > 180)
        relativeYaw -= 360;

      if (relativeYaw < -180)
        relativeYaw += 360;

      if (relativeRoll > 180)
        relativeRoll -= 360;

      if (relativeRoll < -180)
        relativeRoll += 360;

      /////////////////////////////////////////////////////
      // DEADZONE
      /////////////////////////////////////////////////////

      if (abs(relativeYaw) < 1.0)
        relativeYaw = 0;

      if (abs(relativeRoll) < 1.0)
        relativeRoll = 0;

      /////////////////////////////////////////////////////
      // LIMITS
      /////////////////////////////////////////////////////

      relativeYaw = constrain(
        relativeYaw,
        -90,
        90
      );

      relativeRoll = constrain(
        relativeRoll,
        -45,
        45
      );

      /////////////////////////////////////////////////////
      // ASSIGN DATA
      /////////////////////////////////////////////////////

      data.yaw = relativeYaw;
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

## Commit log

2026-04-30 Add ESP32 code for IMU and servo control
2026-04-30 Add code for Visor TX (IMU GY-BNO085)
2026-04-30 Add code for Visor RX (Servo)
2026-04-30 Added circuit diagram image
2026-05-01 Submitted code for H Bridge and Motor setup
2026-05-01 Add materials section to README
    Added materials section with a link to the material list.
2026-05-05 Added diagram for connecting the FS-iA6B to ESP32
2026-05-05 Added diagram for connecting the motors and IBT_2 h-bridge
2026-05-06 Submitted Diagram for 2 Servos
2026-05-06 Update Visor RX (ESP32 + 2 Servos)
2026-05-11 Refactor Visor RX for servo control and data handling
    Refactor Visor RX code for improved servo control and data handling.
2026-05-12 Revise project overview and add materials list
    Updated project overview and materials section in README.md.
2026-05-12 Refactor IBT-2 motor control for dual motor setup
    Refactor motor control for IBT-2 to support left and right motors separately. Update channel handling for throttle and steering.
2026-05-12 Update Motor Movement (Controller FS-i6X + Rx FS-iA10B)
2026-05-12 Fix comment for IBT-2 motor direction
2026-05-15 Clarify controller in comments for motor movement
    Updated comments to clarify the controller used.
2026-05-15 Rename FS-iA6B - ESP32.png to Image - FS-iA6B to ESP32.png
2026-05-15 Rename Motors JGB37-520B + H Bridge IBT_2.png to Image - Motors JGB37-520B + H Bridge IBT.png
2026-05-15 Rename Circuit Diagram.png to Image - Circuit Diagram.png
2026-05-15 Add Visor RX code for Servo MG995 and IMU GY-BNO085
2026-05-15 Revise README with new content and images
    Updated project description, added links for paper and showcase, and modified material list.
2026-05-15 Update README with showcase link and materials
    Added a link to a showcase video of the robot's development and included a new resistor in the materials list.
2026-05-16 Revise development progress documentation formatting
    Updated formatting and content in the development progress documentation. Enhanced clarity of CAD design and electronics sections.
2026-05-18 Rename Image - Visor TX (Esp32 + IMU) to Code - Visor TX (Esp32 + IMU)
2026-05-19 Update Code - Visor TX (Esp32 + IMU)
2026-05-19 Refactor ESP-NOW RX and servo control logic
    Refactor servo control logic and improve data handling.
2026-05-19 Documentación en inglés del sistema de visión
2026-05-20 Update Code - Visor RX (Esp32 + Servo)
2026-05-21 Refactor motor control logic and improve comments
2026-05-21 Rename motor control code directory
2026-05-21 Rename Code - Visor RX (Esp32 + Servo) to Code - Visor RX (Esp32 + Servo)
2026-05-21 Move code files to Camera Head Tracking directory
2026-05-21 Rename Code - Visor RX (Esp32 + Servo) to Code - Visor RX (Esp32 + Servo).ino
2026-05-21 Rename Code - Visor TX (Esp32 + IMU) to Code - Visor TX (Esp32 + IMU).ino
2026-05-21 Rename Code - H Bridge + Motors JGB37-520B + Controller to Code - H Bridge + Motors JGB37-520B + Controller.ino
2026-05-22 Version para probar en jetson
2026-06-03 Este es el que debes tomar como base Alan :)
2026-06-04 CÓDIGO PARA CORRER TODO EN LA JETSON AUTOMATICAMENTE
2026-06-09 Revise README with new images and material details
    Updated images and material list in README.md. Adjusted future goals for clarity.
2026-06-09 Integrate ESP-NOW for head tracking and motor control
    Refactor code to integrate ESP-NOW for head tracking and motor control. Update servo and motor configurations, and improve channel handling.
2026-06-09 Update receiver MAC address and I2C pin configuration
